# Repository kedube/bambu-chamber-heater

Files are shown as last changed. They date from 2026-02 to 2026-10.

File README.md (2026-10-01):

# Bambu Chamber Heater - ESPHome Temp Controller
ESPHome implementation to remotely control **Sinilink XY-SA/ST series temperature controllers** for *Bambu Lab P1S/X1 Carbon 3D printers*. The repository now supports both the **ESP8285-based XY-WFPOW** module and the **Waveshare ESP32-C6-Zero** from one shared codebase.

This project allows you to automatically manage a chamber heater, link it to print jobs, and control it through Home Assistant or the built-in web interface. It was inspired by the [BambuSauna project](https://makerworld.com/en/models/2417482-bambusauna-for-sinilink-xy-sa-st-temp-controller).

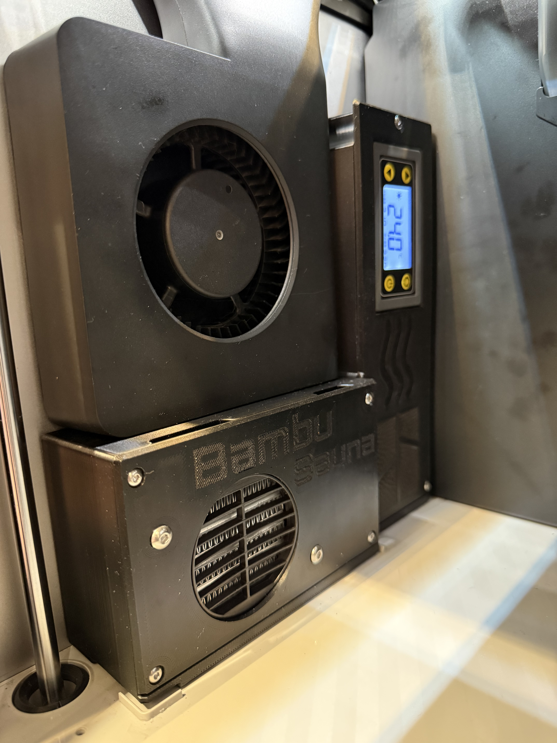
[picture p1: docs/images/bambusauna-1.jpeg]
Assembled BambuSauna chamber heater installed on a Bambu Lab printer

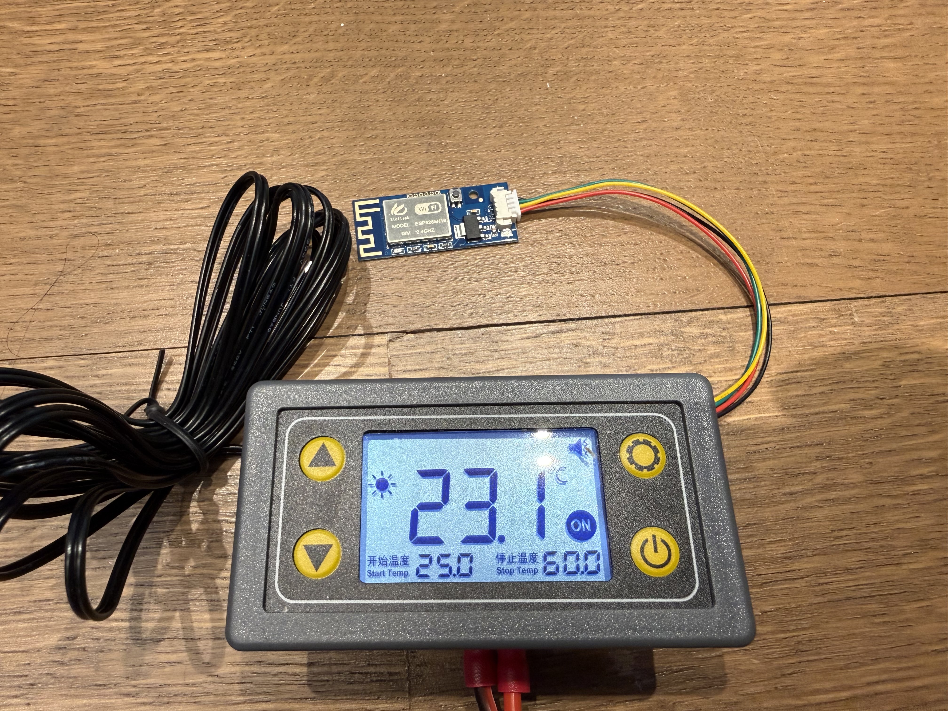
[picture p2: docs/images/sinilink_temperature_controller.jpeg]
Sinilink XY-SA temperature controller module


## Table of Contents

- [Supported Devices](#supported-devices)
- [Features](#features)
- [Filament Presets](#filament-presets)
- [Repository Layout](#repository-layout)
- [Requirements](#requirements)
- [References](#references)
- [Modbus Address Map](#modbus-address-map)
- [Wiring Diagram and Installation Notes](#wiring-diagram-and-installation-notes)
- [Setup](#setup)
  - [1. Install ESPHome](#1-install-esphome)
  - [2. Clone the Repository](#2-clone-the-repository)
  - [3. Configure Secrets](#3-configure-secrets)
  - [4. Choose Device and Temperature Unit](#4-choose-device-and-temperature-unit)
  - [5. Validate the Configuration](#5-validate-the-configuration)
  - [6. Build](#6-build)
  - [7. First Flash](#7-first-flash)
  - [8. Web UI](#8-web-ui)
  - [9. Home Assistant](#9-home-assistant)
- [Troubleshooting](#troubleshooting)
- [Known Issues](#known-issues)
- [Safety](#safety)
- [License](#license)
- [Contributing](#contributing)

## Supported Devices

| Device | ESPHome Entry File | Notes |
| :--- | :--- | :--- |
| ESP8285 / XY-WFPOW | `esphome/temp_controller_esp8285.yaml` | Original Sinilink Wi-Fi module, built-in status LED, no fan RPM monitoring |
| ESP32-C6-Zero | `esphome/temp_controller_esp32.yaml` | External module retrofit, WS2812 status LED, fan RPM monitoring, Wi-Fi protocol sensor |
| Manual selector | `esphome/temp_controller.yaml` | Main YAML with package toggles for device and temperature unit |

## Features

### Shared Features
- ESPHome integration for Home Assistant
- Standalone web interface
- Automatic chamber temperature control based on print state and filament type
- [Filament presets](#filament-presets) plus user-defined mode
- Emergency stop handling
- Over-temperature protection
- Runaway heating detection
- Sensor fault detection
- Modbus communication watchdog
- End-of-job shutoff
- Celsius and Fahrenheit builds
- OTA firmware updates

### ESP32-C6-Zero Extras
- RPM monitoring for 3-wire fans with emergency-stop interlock
- Wi-Fi 6 support with protocol diagnostic sensor via [include/wifi_protocol_helper.h](include/wifi_protocol_helper.h)
- WS2812 RGB status LED (GPIO8) with state-based colors and effects:

| LED State | Color | Effect | Meaning |
|---|---|---|---|
| Emergency Stop | Red | Solid | System emergency stopped |
| WiFi Disconnected | Blue | Fast Pulse | Network connection lost |
| Over Temperature | Red | Strobe | Temperature >60°C warning |
| Heating Active | Orange | Slow Pulse | Heater is running |
| Normal/Idle | Green | Solid (dim) | Everything OK |

The LED updates automatically via state-change triggers (for example Wi-Fi connect/disconnect) plus periodic refresh, providing at-a-glance status without needing to check the web interface or Home Assistant.

## Filament Presets

When a print starts, the controller reads the active filament type from the Bambu Lab Home Assistant integration and automatically selects the matching chamber temperature preset. You can also select a preset manually (including for pre-heating before a print), or use **User-defined** mode to set your own thresholds. Selecting **Off** engages the emergency stop.

Each preset targets the temperature below with a ±1°C hysteresis band (for example, PLA at 22°C starts heating at 21°C and stops at 23°C) to prevent rapid relay cycling. The defaults are defined as substitutions in [esphome/settings.yaml](esphome/settings.yaml) — adjust them there for your filament brands, printer, and enclosure.

| Preset | Default Target (°C) | Preset | Default Target (°C) |
| :--- | :---: | :--- | :---: |
| PLA | 22 | PA | 60 |
| TPU | 25 | PA6 | 80 |
| PETG | 35 | PA12 | 60 |
| PCTG | 35 | PA612 | 25 |
| ABS | 55 | PPA | 70 |
| ASA | 55 | PPS | 80 |
| PC | 80 | PP | 55 |
| PET | 50 | PE | 75 |
| | | PAHT | 55 |

## Repository Layout

- `esphome/settings.yaml` contains the shared substitutions, default build settings, and additional shared configuration options you may want to customize.
- `esphome/packages/controller_shared.yaml` contains the shared controller logic, Modbus entities, automations, and safety behavior.
- `esphome/packages/device_esp8285.yaml` contains ESP8285-only framework, GPIO, and hardware configuration.
- `esphome/packages/device_esp32.yaml` contains ESP32-C6-Zero-only framework, GPIO, fan monitoring, LED logic, and helper include usage.
- `esphome/packages/celsius.yaml` and `esphome/packages/fahrenheit.yaml` contain unit-specific number ranges and preset math.
- `esphome/temp_controller.yaml` is the main entrypoint if you want to switch device and unit by editing one file.
- `include/` contains the shared C++ helper headers used by the YAML lambdas (see [include/README.md](include/README.md)).
- `assets/web/` contains the custom web UI CSS and JavaScript assets used by ESPHome's web server.
- `docs/images/` contains README screenshots, wiring diagrams, and source artwork; `docs/home-assistant-dashboard.md` has a ready-made Lovelace dashboard.
- `hardware/3d-models/` contains printable enclosure and adapter `.3mf` files (print in ASA or PC — see [3D Printed Parts](#3d-printed-parts)).
- `test/` contains host-side unit tests for the helper headers (`./test/run_tests.sh`).
- `.github/workflows/ci.yml` runs the unit tests, validates every device/unit combination, and compiles both device targets on each push.
- `CHANGELOG.md` tracks notable changes for each tagged release.

## Requirements

### Software
- ESPHome installed locally _(validated against ESPHome 2026.9.0 in CI — see [.github/workflows/ci.yml](.github/workflows/ci.yml); older releases may need YAML adjustments)_
- Home Assistant with the [Bambu Lab HA integration](https://github.com/greghesp/ha-bambulab)

### Common Hardware
- Bambu P1S / X1 Carbon 3D Printer
- Sinilink XY-SA10/SA30-W AC 110V-250V Temperature Controller _(the SA10 is sufficient — its 10A relay rating is roughly five times the ~2A a 250W heater draws; the SA30's higher rating is unnecessary here)_
- NOYITO AC 100V-264V to DC 24V 1A Power Supply Module _(powers the 24V Fan only)_
- AC 120/240V PTC Heater 200-250W _(no need to be more powerful than this)_
- (2) 3-Way WAGO Connectors
- 16-18Ga silicone wiring _(Used: red and black wiring)_
- Heat set inserts: (15) M3x4x5 + (1) M2x2.5x3.2
- Screws:
  - (7) M3x5MM or 6MM button screws for covers
  - (2) M3x25MM hex head screws for lower aux fan screws
  - (4) M3x25MM hex head screws for 24V Fan
  - (4) M3x4MM button screws for NOYITO AC to DC Power Supply Module
  - (2) M3x8MM hex head screws to connect housing to printer bottom
  - (4) M4x6MM or 8MM self-tapping screws to hold PTC in housing without fan
  - (2) M4x12MM button screws to hold the PTC heater to the front cover
  - (2) M4 self-locking nuts to connect the PTC heater to the front cover
  - (1) M2x3MM machine screw to hold the wireless module to the housing
- (1) XT30 connector pair set (both ends) _(so the chamber heater can be unplugged and removed from the printer)_
- Heatshrink tubing _(for XT30 connectors)_
- Soldering equipment _(depending on the installation method)_

### ESP8285 Hardware
- Sinilink XY-WFPOW (ESP8285-based) wireless module
- 24V 4020 2-wire fan _(Used: SUNON MF40202VX-1000U-A99 with 10.8CFM airflow)_
- USB-to-TTL UART programmer _(only needed for the initial flash; highly recommend FTDI-based programmers)_

### 3D Printed Parts
Print the enclosure and adapter parts in `hardware/3d-models/` in **ASA or PC only**. The housing sits against a 200-250W PTC heater and a printer that may itself run a heated chamber — PLA and PETG will soften and deform at these temperatures.

### ESP32-C6-Zero Hardware
- Waveshare ESP32-C6-Zero with 2 x 9-pin headers soldered
- 24V 4020 3-wire fan _(Used: SUNON MF40202VX-1000U-G99 with 10.8CFM airflow)_
- 1/4W 10K resistor _(for 3.3V pull-up power for tach)_
- JST MX 1.25mm 4-pin cable to connect ESP32 to Temperature Controller
- Assorted 2.54mm pitch housings and crimp pins to terminate JST MX 4-Pin cable
- USB-C-to-USB-C cable for the initial flash

## References
- [Sinilink XY-ST/SA Remote Thermostat Datasheet](https://myosuploads3.banggood.com/products/20240220/20240220213226STSA-EN.pdf)
- [Sinilink XY-WT04 Modbus Communication Protocol](https://myosuploads3.banggood.com/products/20220717/20220717212911XY-WT04-EN.pdf)
- [ESPhome-Sinilink-XY-WFPOW](https://github.com/creepystefan/ESPhome-Sinilink-XY-WFPOW)
- [Tasmota XY-WFPOW Template](https://templates.blakadder.com/sinilink_XY-WFPOW.html)

## Modbus Address Map

| ADDRESS | TYPE | NAME | RANGE/VALUES | Read/Write | DESCRIPTION |
| :--- | :---: | :--- | :--- | :---: | :--- |
| 0x0000 | U_WORD | Controller Status | 0=Stopped, 1=Active | RW | Main relay/controller state |
| 0x0001 | U_WORD | Temp Sensor Status | 0=Connected, 1=Disc | RO | Temperature sensor connection status |
| 0x0002 | U_WORD | Delay Time Remaining | 0-999 seconds | RO | Countdown timer for delayed start |
| 0x0003 | S_WORD | Current Temperature | -400 to 1100 (*0.1) | RO | Current measured temperature |
| 0x0004 | U_WORD | Temperature Unit | 0=Celsius, 1=Fahrenheit | RW | Display and control temperature unit |
| 0x0005 | U_WORD | Controller Mode | 0=Heating, 1=Cooling | RO | Operating mode |
| 0x0006 | S_WORD | Low Temp Threshold | -400 to 850 (*0.1) | RW | Temperature to start heating/cooling |
| 0x0007 | S_WORD | High Temp Threshold | -400 to 850 (*0.1) | RW | Temperature to stop heating/cooling |
| 0x0008 | S_WORD | High Temp Alarm | -400 to 1100 (*0.1) | RW | High temperature alarm threshold |
| 0x0009 | S_WORD | Low Temp Alarm | -400 to 1100 (*0.1) | RW | Low temperature alarm threshold |
| 0x000A | U_WORD | Delay Start Time | 0-999 seconds | RW | Delay start duration setting |
| 0x000B | S_WORD | Temperature Offset | -100 to 100 (*0.1) | RW | Temperature calibration offset |
| 0x000C | BOOL | Alarm Active | 0=No, 1=Yes | RO | Temperature alarm status |
| 0x000D | BOOL | Alarm Sound | 0=Off, 1=On | RW | Enable/disable alarm beeper |
| 0x000E | BOOL | High Temp Alarm Enable | 0=Off, 1=On | RW | Enable high temperature alarm |
| 0x000F | BOOL | Low Temp Alarm Enable | 0=Off, 1=On | RW | Enable low temperature alarm |
| 0x0010 | BOOL | Delay Start Enable | 0=Off, 1=On | RW | Enable delayed start feature |
| 0x0011 | BOOL | Emergency Stop | 0=Off, 1=On | RW | Emergency stop/disable controller |
| 0x0012 | U_WORD | Modbus Address | 1-247 | RW | Modbus slave address |
| 0x0013 | U_WORD | Modbus Baudrate | 0-6 | RW | Serial communication speed |
| 0x0014 | BOOL | Sleep Mode | 0=Off, 1=On | RW | Display sleep/power saving mode |
| 0x0015 | U_WORD | Backlight Level | 0-7 | RW | Display backlight brightness |

Baudrate map for `0x0013`: `0=9600`, `1=14400`, `2=19200`, `3=38400`, `4=56000`, `5=57600`, `6=115200`.

Temperature Value Encoding:
   - Stored as signed 16-bit integers representing temperature in tenths of degrees
   - Actual temperature = register_value * 0.1
   - Example: register value 235 = 23.5°C

Safety Notes:
   - Always enable high temp alarm (0x000E) for safety
   - Set high temp alarm (0x0008) above normal operating range
   - Emergency stop (0x0011) immediately disables heating/cooling

## Wiring Diagram and Installation Notes

### ESP8285 / XY-WFPOW
Use the original Sinilink XY-WFPOW Wi-Fi module. The basic wiring diagram is shown below.

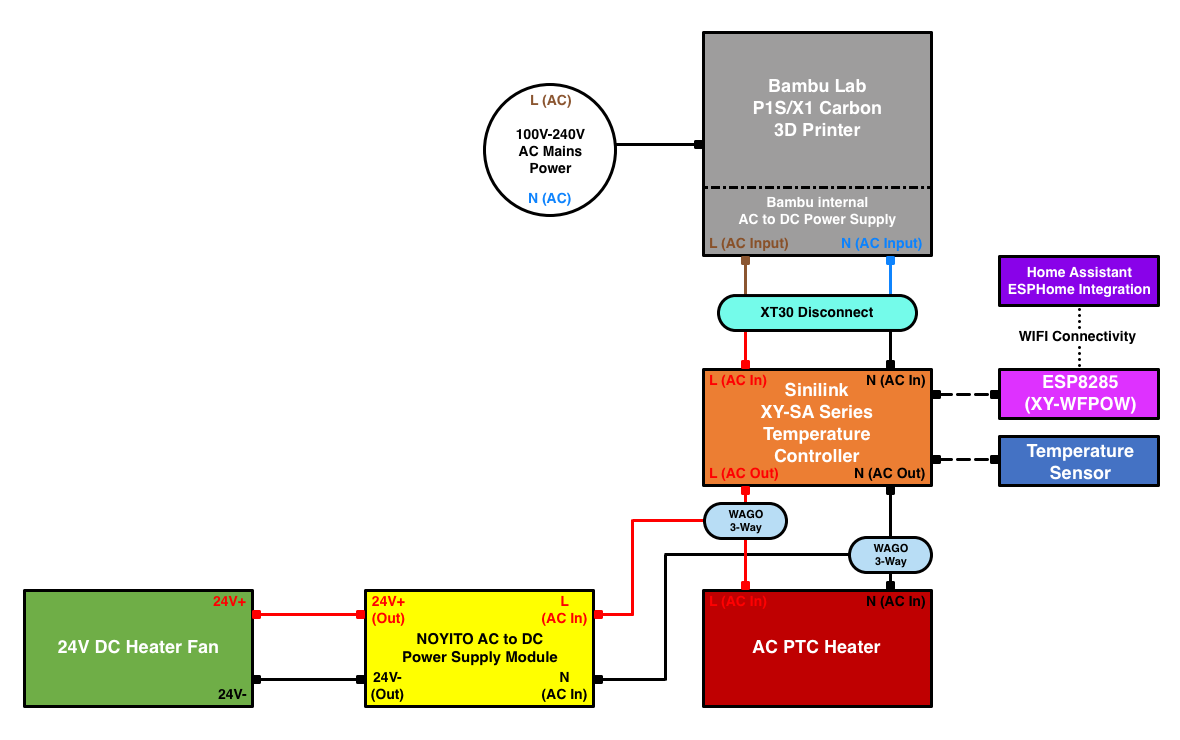
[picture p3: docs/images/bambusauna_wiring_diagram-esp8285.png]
ESP8285 / XY-WFPOW wiring diagram

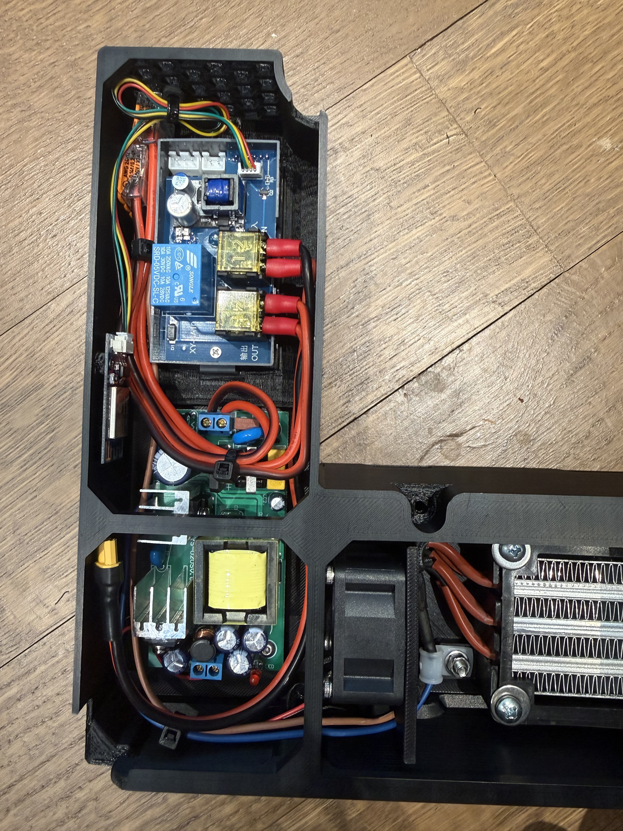
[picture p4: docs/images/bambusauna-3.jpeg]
Heater housing interior showing the Sinilink controller and wiring

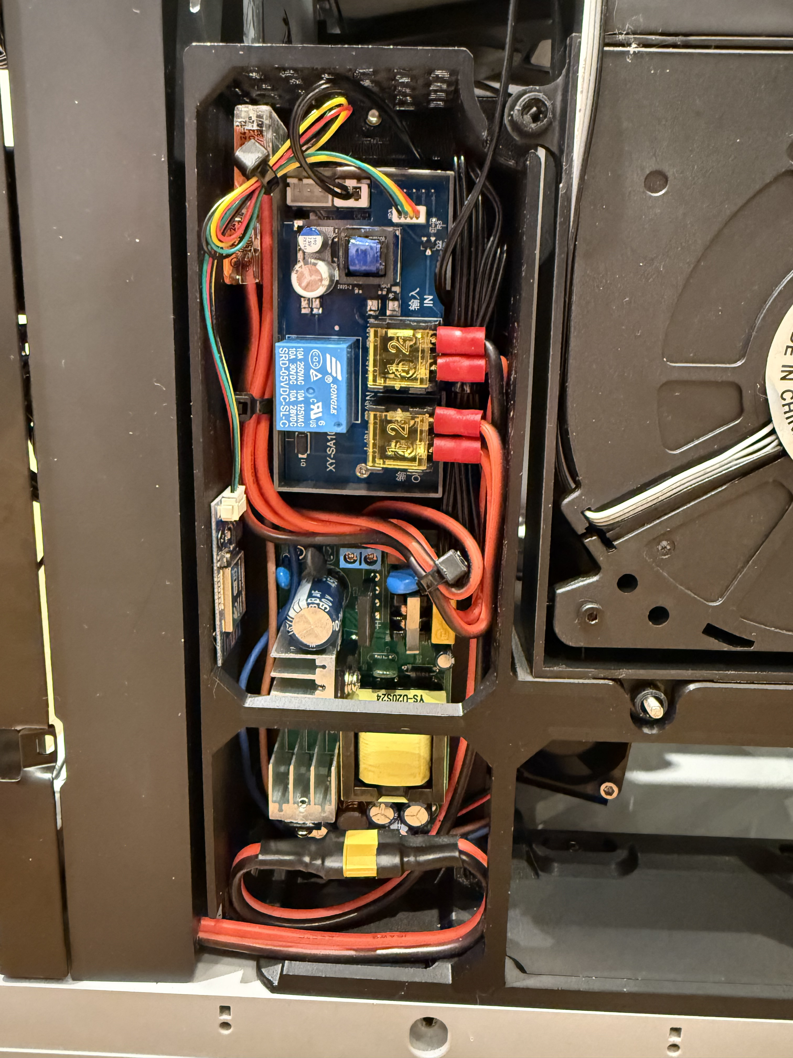
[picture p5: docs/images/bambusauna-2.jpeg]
Assembled heater housing mounted beneath the printer


### ESP32-C6-Zero
The ESP32-C6-Zero retrofit uses a separate module and adds fan RPM monitoring and RGB LED status indication.

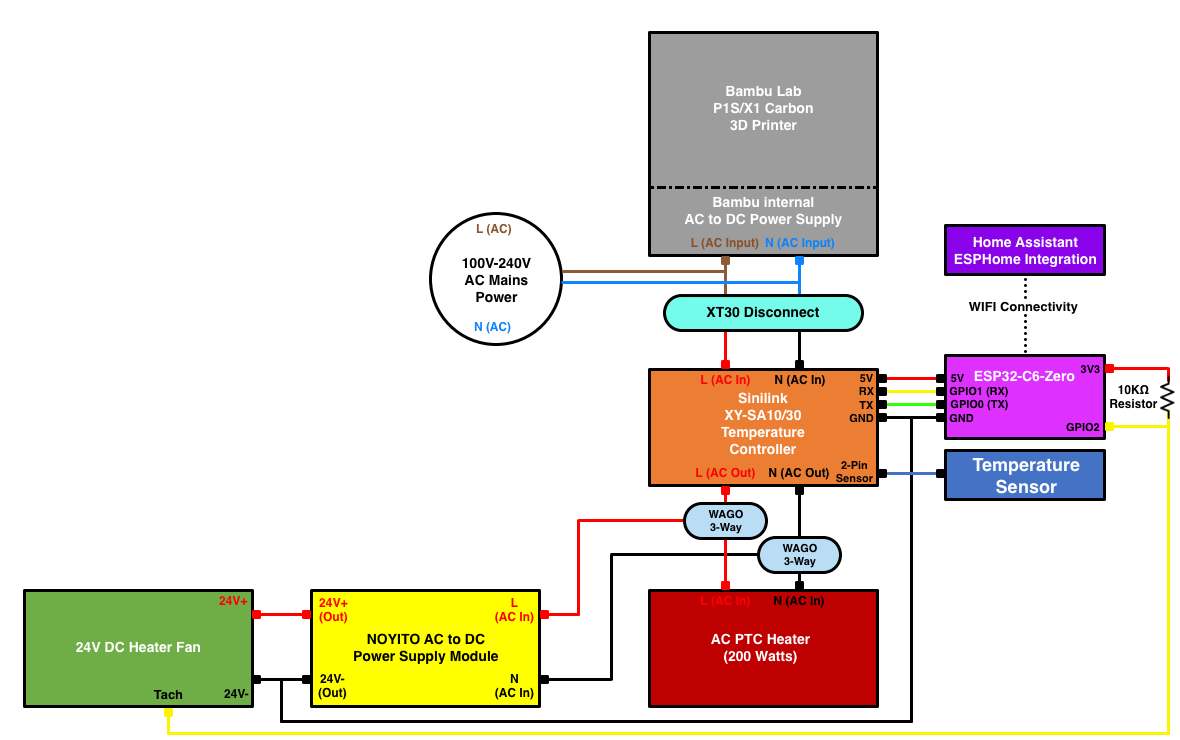
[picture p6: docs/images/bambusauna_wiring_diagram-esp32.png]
ESP32-C6-Zero wiring diagram

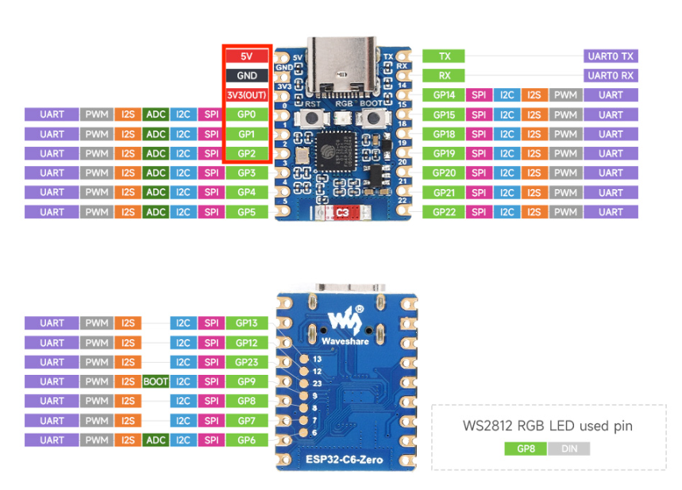
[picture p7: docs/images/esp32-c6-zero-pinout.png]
Waveshare ESP32-C6-Zero pinout reference

ESP32-C6-Zero wiring harness with JST connector
Heater housing interior with the ESP32-C6-Zero installed
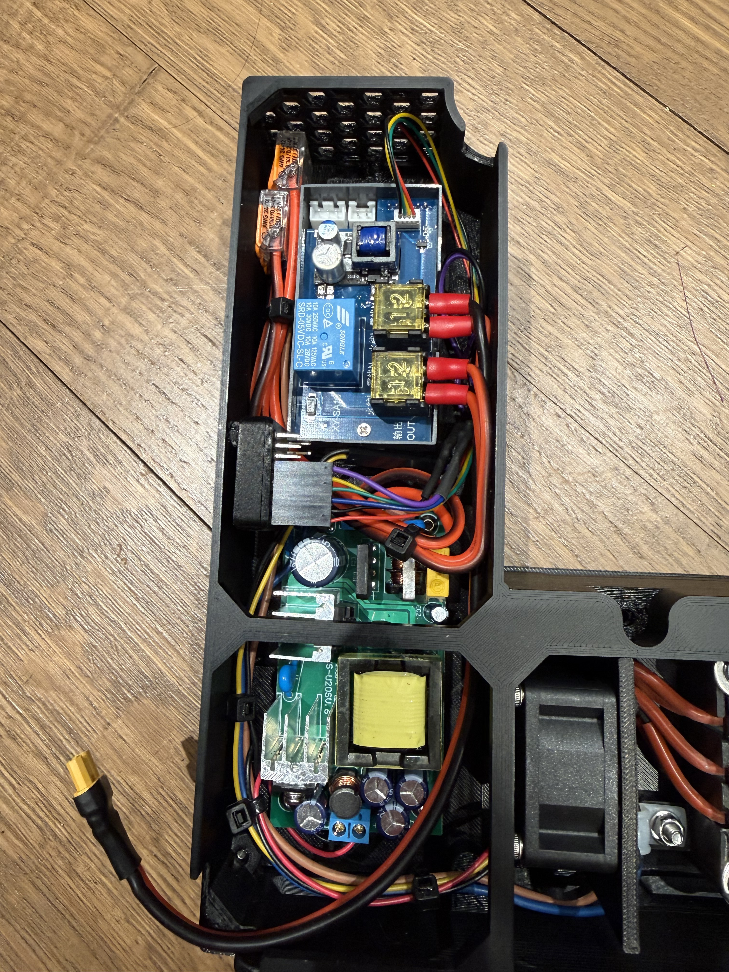
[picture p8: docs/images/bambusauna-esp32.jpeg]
Close-up of the ESP32-C6-Zero module mounted in the housing


## Setup

### 1. Install ESPHome
Follow the official directions on the [ESPHome website](https://esphome.io/guides/installing_esphome/).

On macOS, the easiest path is [Homebrew](https://brew.sh/). If you don't already have Homebrew, install it first:
```bash
/bin/bash -c "$(curl -fsSL https://raw.githubusercontent.com/Homebrew/install/HEAD/install.sh)"
```

Then install ESPHome:
```bash
brew install esphome
```

### 2. Clone the Repository

```bash
git clone https://github.com/kedube/bambu-chamber-heater
cd bambu-chamber-heater
```

### 3. Configure Secrets
Copy and edit the secrets file:

```bash
cp esphome/secrets-example.yaml esphome/secrets.yaml
```

Important values include:
- `wifi_ssid`
- `wifi_password`
- `ap_wifi_ssid`
- `ap_wifi_password`
- `web_server_username`
- `web_server_password`
- `ota_password`
- `encryption_key`
- `bambu_printer_id`

The example file also contains commented-out keys (`static_ip`, `gateway`, `subnet`, `dns1`, `dns2`) for an optional static IP configuration — uncomment them (and the matching `manual_ip:` block in `esphome/packages/controller_shared.yaml`) if you need one.

Shared substitutions such as `device_name`, `friendly_name`, software version, and filament preset defaults are defined in `esphome/settings.yaml`.
Most runtime behavior, Modbus transport settings, and automations are defined in `esphome/packages/controller_shared.yaml`.
Use those files for shared configuration changes before editing device-specific packages.

Generate a valid 32-byte encryption key (see: [ESPHome.io](https://esphome.io/components/api/)), and insert it under `encryption_key`.

### 4. Choose Device and Temperature Unit

If you want one editable selector file, use `esphome/temp_controller.yaml` and switch the package includes:

```yaml
packages:
  settings: !include settings.yaml
  controller_shared: !include packages/controller_shared.yaml
  select_units: !include
    file: packages/celsius.yaml
    #file: packages/fahrenheit.yaml
  select_device: !include
    file: packages/device_esp8285.yaml
    #file: packages/device_esp32.yaml
```

If you prefer a fixed compile target, use one of these:
- `esphome/temp_controller_esp8285.yaml`
- `esphome/temp_controller_esp32.yaml`

### 5. Validate the Configuration

```bash
esphome config esphome/temp_controller.yaml
```

### 6. Build

Example:

```bash
esphome run esphome/temp_controller.yaml
```

### 7. First Flash

Once ESPHome successfully compiles the YAML configuration, it will prompt you to flash the module. For the first flash, the device must be connected to your computer to upload the firmware.

#### ESP8285 / XY-WFPOW
For the ESP8285, use the USB-to-TTL adapter programmer at **3.3V** and the XY-WFPOW flashing pins:

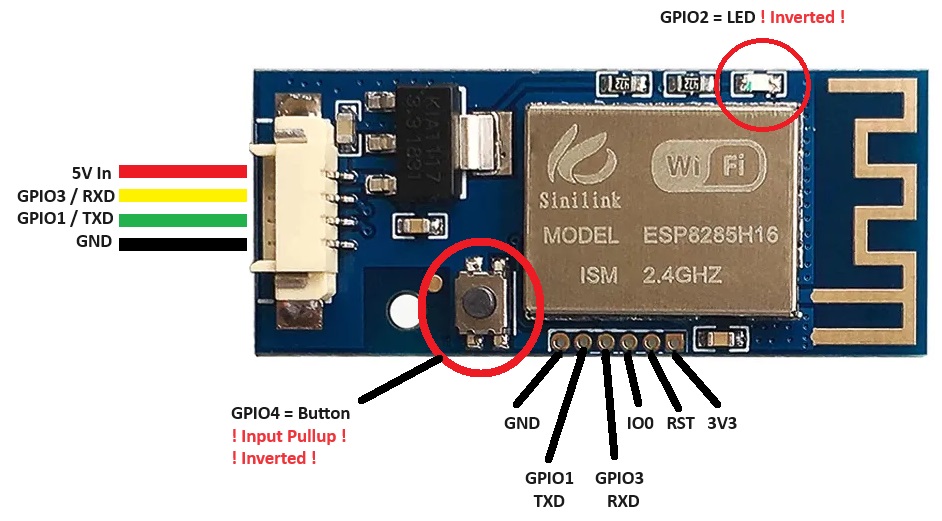
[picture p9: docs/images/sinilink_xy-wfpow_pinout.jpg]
Sinilink XY-WFPOW flashing pinout (source: creepystefan/ESPhome-Sinilink-XY-WFPOW)

```text
GND -> GND
TXD -> RXD
RXD -> TXD
IO0 -> GND
RST -> not connected
3V3 -> VCC
```

Adapter board photos:
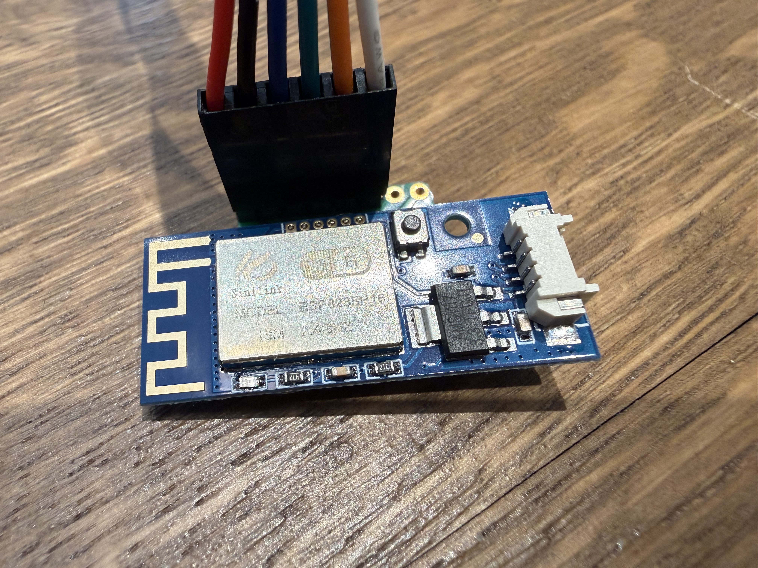
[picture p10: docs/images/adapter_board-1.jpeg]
USB-to-TTL programming adapter board, top view

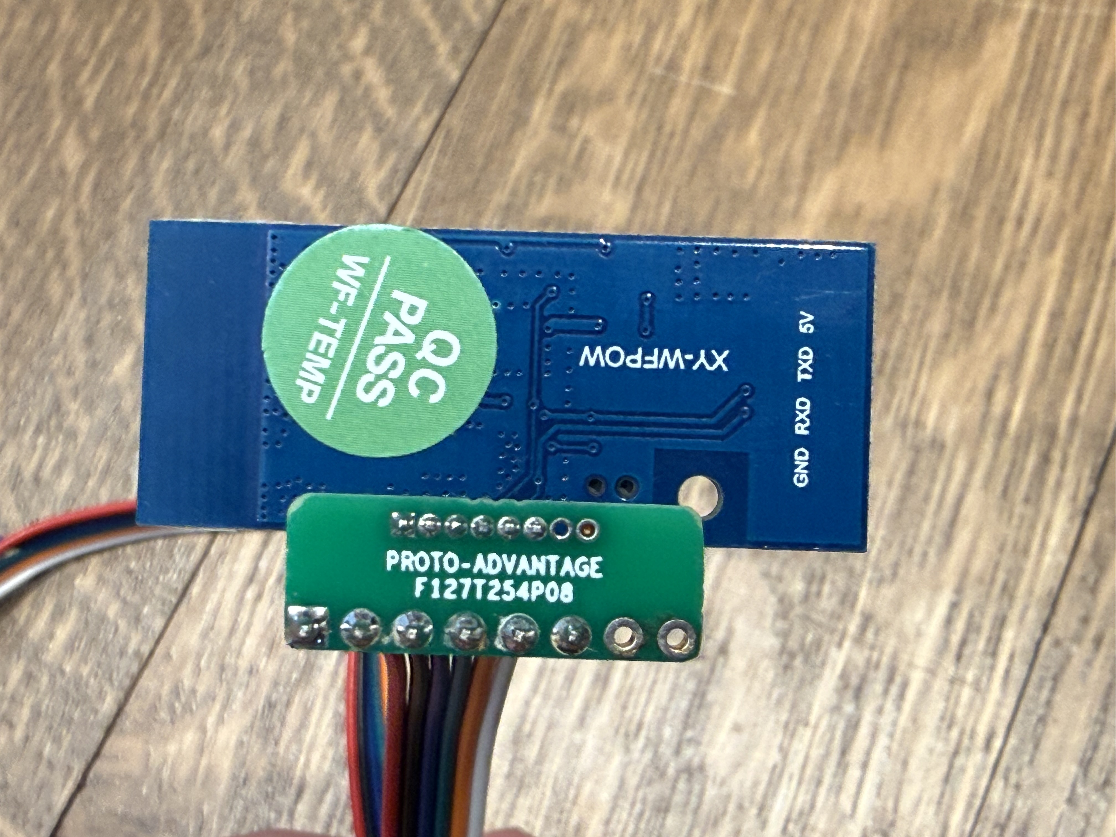
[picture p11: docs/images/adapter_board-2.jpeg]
USB-to-TTL programming adapter board connected to the XY-WFPOW


#### ESP32-C6-Zero
For the ESP32-C6-Zero, you must connect the board via USB-C and flash it directly. It will prompt you after a successful build for where to upload the code. Once running, the onboard WS2812 RGB LED shows live system status — see the [LED state table](#esp32-c6-zero-extras) under Features.

#### Upload Firmware Over USB With ESPHome

```text
INFO Build Info: config_hash=0x694d2e36 build_time_str=2026-04-01 14:02:17 -0400
INFO Successfully compiled program.
Found multiple options for uploading, please choose one:
  [1] /dev/cu.usbserial-8320 (USB Serial)
  [2] Over The Air (esp32-remote.local)
(number):
```

#### Subsequent Flashes
After the initial flash, both device types can be updated over the air (OTA) using ESPHome.

### 8. Web UI
A local web server starts on port `80` after installation. You can access it from a browser on your local network using the username and password configured in `secrets.yaml`.

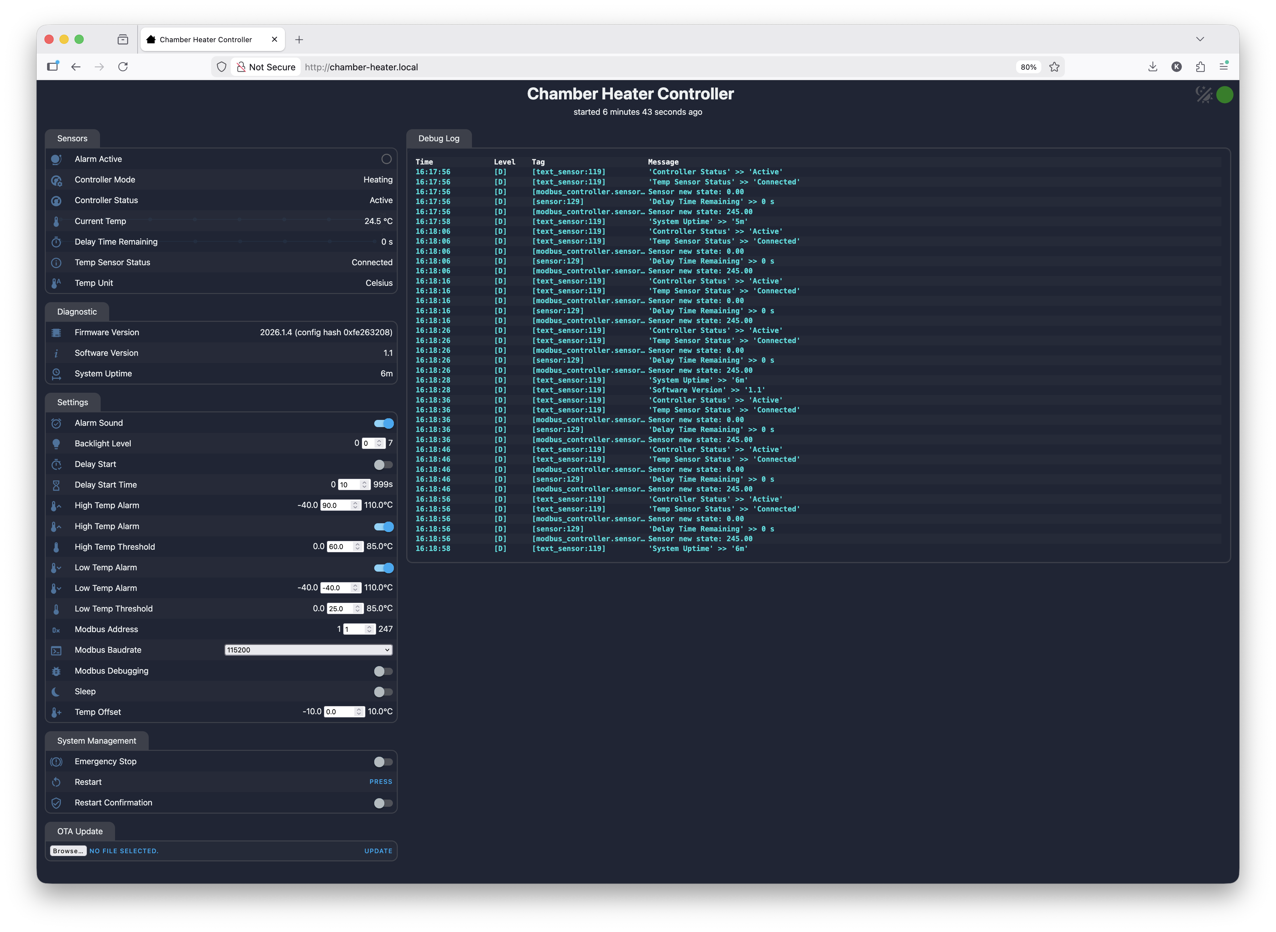
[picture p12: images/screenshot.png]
Chamber heater web interface showing sensors, settings, and system controls


The web UI's animated background is selectable in `esphome/packages/controller_shared.yaml` under `web_server:` → `js_include`. Three effects ship in `assets/web/`: `pixel-stars.js` (default), `moving-particles.js`, and `shooting-stars.js` — uncomment the one you want (only one at a time) and re-flash.

### 9. Home Assistant
Once online, the device should be discovered by the ESPHome integration in Home Assistant. Use the same `encryption_key` configured in `esphome/secrets.yaml`.

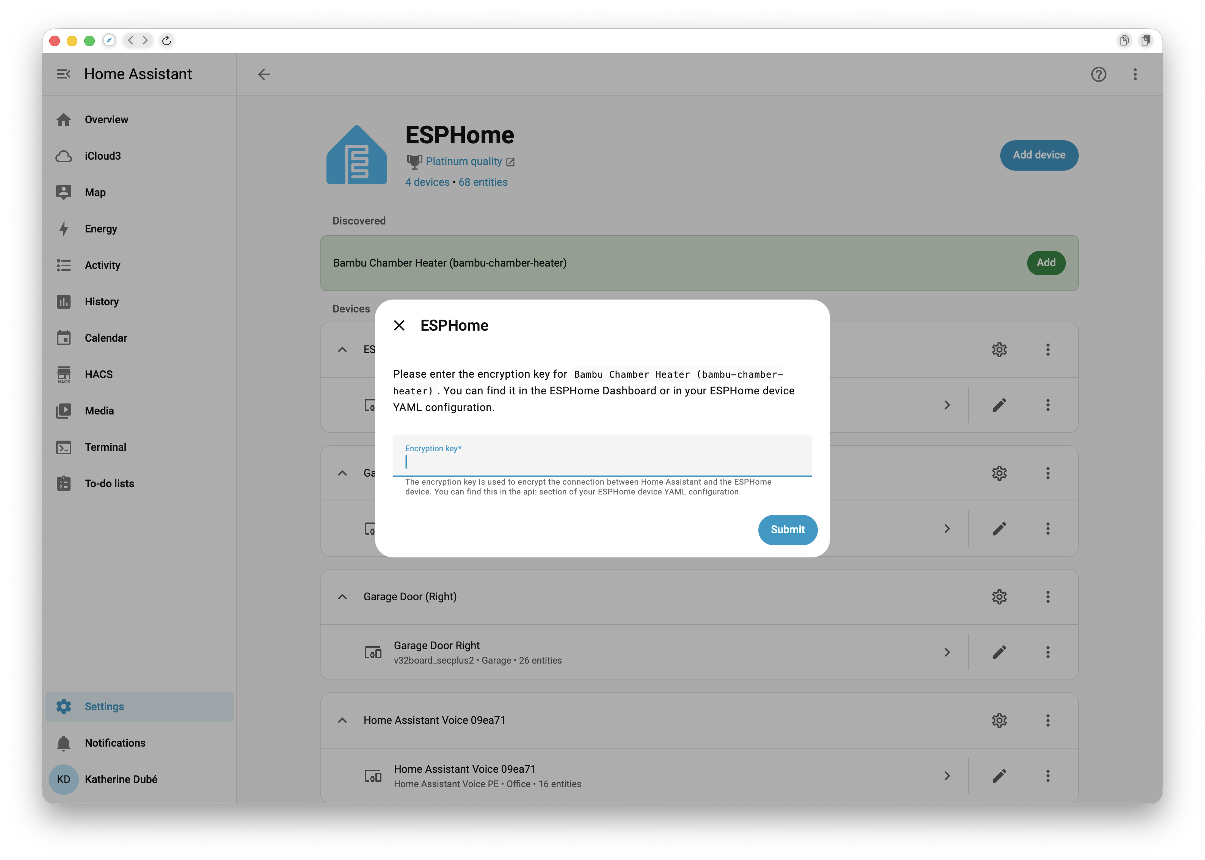
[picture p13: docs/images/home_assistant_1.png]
Home Assistant prompting for the ESPHome encryption key

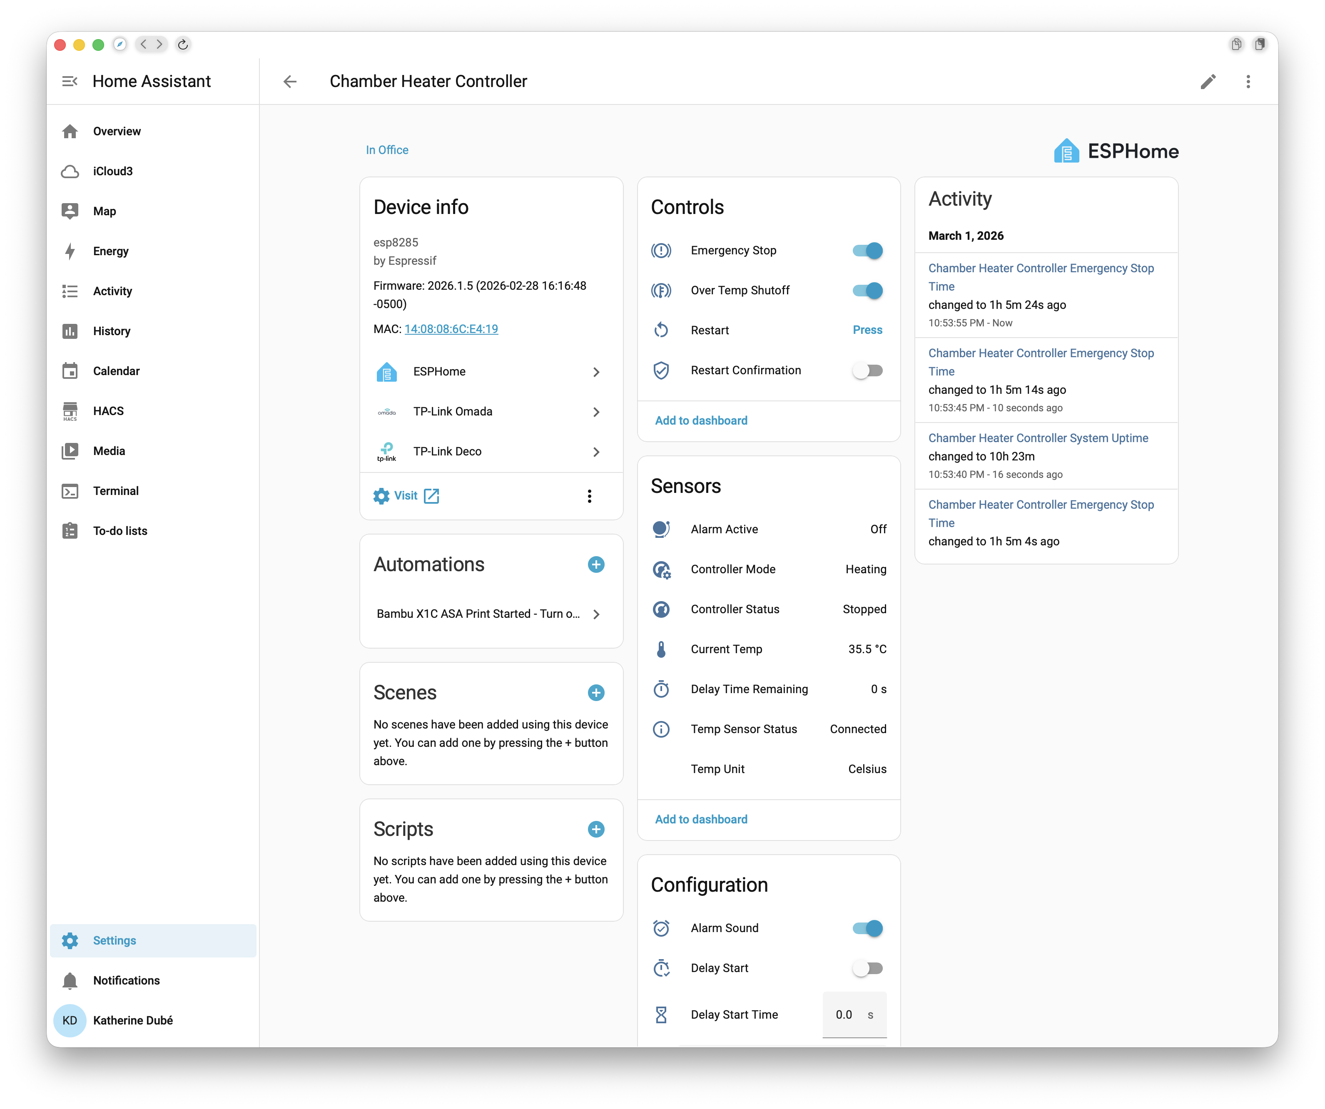
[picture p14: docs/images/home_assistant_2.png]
Home Assistant device page listing the chamber heater entities


For a ready-made dashboard layout (gauge, controls, and safety diagnostics), see [docs/home-assistant-dashboard.md](docs/home-assistant-dashboard.md).

## Troubleshooting

**The device boots with Emergency Stop engaged.** This is by design — the heater always starts disarmed. Select a filament preset (or clear the Emergency Stop switch) to begin heating.

**Emergency Stop is on and selecting a preset doesn't clear it.** When the stop was triggered by a fault — thermal runaway, a temperature alarm, a disconnected sensor, Modbus communication loss, a fan failure, the printer going offline, or Home Assistant disconnecting — presets intentionally cannot clear it (the log shows *"Emergency stop remains active because it was triggered by a fault condition"*). Fix the underlying issue, then manually turn off the **Emergency Stop** switch in the web UI or Home Assistant to acknowledge the fault. The **Emergency Stop Time** sensor (System Management group) shows how long ago it tripped, and the device logs record the cause on lines tagged `EMERGENCY`.

**Heater won't turn on.** Check, in order: the **Filament Temp Preset** isn't `Off`; **Emergency Stop** is off; **Delay Start** isn't holding the relay (watch **Delay Time Remaining**); and the current temperature isn't already above the **High Temp Threshold**. Note that when the printer reports an inactive state (finish, failed, offline, or idle), the end-of-job shutoff forces the preset back to `Off` — you can still pre-heat manually by selecting a preset, but a printer state change to inactive will turn it off again.

**"No temperature updates" emergency stop (Modbus watchdog).** The watchdog trips if no temperature reading arrives for 90 seconds. Verify the UART wiring (TX/RX not swapped), that the controller's baud rate matches the build default of 115200, and that the Modbus address is 1. Turn on the **Modbus Debugging** switch to log the raw hex frames and confirm whether the controller is responding.

**Fan failure emergency stop, or Fan RPM reads 0 (ESP32-C6-Zero).** A fan fault trips when RPM stays below 200 for 10 seconds while the heater is active. Confirm the fan is a 3-wire model with a tachometer lead, the tach line has its 10K pull-up to 3.3V, and the JST harness is seated. The thresholds (`fan_min_rpm`, `fan_fail_timeout_seconds`) are adjustable in `esphome/settings.yaml`.

**Emergency stop whenever Home Assistant restarts or drops off the network.** Losing the Home Assistant API connection (or the printer's `_online` sensor going off) is treated as a fail-safe condition because print-state automation is no longer available. This is expected; clear the stop once Home Assistant reconnects. Check the **WIFI Signal Strength** sensor if it happens frequently.

**Can't reach the web UI.** If the device can't join your Wi-Fi it starts a fallback access point (default SSID `chamber-heater`, configurable via `ap_wifi_ssid`) with a captive portal for reconfiguration. The web UI itself is on port 80 and uses the credentials from `secrets.yaml`.

**The Restart button does nothing.** Turn on the **Restart Confirmation** switch first, then press **Restart** within 10 seconds — this guards against accidental restarts mid-print.

## Known Issues
- The Sinilink Modbus addresses for the sleep switch (`0x0014`) and backlight level (`0x0015`) do not seem to have any effect on the backlight settings for XY-SA10/SA30 controllers.
- Mixed-material prints will cause the chamber target temperature to fluctuate as the active filament changes.

## Safety
The author assumes no liability for injury, damage, or loss resulting from wiring errors, improper installation, or misuse of this project. Electrical work can be hazardous. If you are unsure, consult a qualified professional.

## License
This project is licensed under the GNU General Public License v3.0 or later — see [LICENSE](LICENSE).

## Contributing
Contributions are welcome for bug fixes, documentation improvements, and new hardware support. Please include testing details when possible, and add user-visible changes to the `## Unreleased` section of [CHANGELOG.md](CHANGELOG.md) — the release automation turns that section into the published release notes.

### Release Process
Releases are fully automated by [.github/workflows/release.yml](.github/workflows/release.yml):

1. Every push to `main` runs [CI](.github/workflows/ci.yml) (unit tests, ESPHome validation for all device/unit combinations, and firmware compiles).
2. When CI passes, the Release workflow bumps the patch segment of `sw_version` in `esphome/settings.yaml`, rotates the CHANGELOG's `## Unreleased` section into the new version, and pushes a `chore(release): <version> [skip ci]` commit.
3. A GitHub release is published for that version, with notes generated from the CHANGELOG section (Highlights), the commit list since the previous tag, and a full-changelog compare link.

To cut a **minor or major** release, set `sw_version` yourself in a normal commit (e.g. `1.9.0`); because that version has no tag yet, the automation publishes it exactly as set, then resumes patch bumps. To re-publish a release for the current version (for example after a failed run), use the Release workflow's **Run workflow** button.

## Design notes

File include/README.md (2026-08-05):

# Helper Headers

C++ helpers included by the ESPHome YAML packages (see the `esphome:` → `includes:` lists in `esphome/packages/`). Keeping this logic in headers keeps the YAML lambdas short and lets both device targets share one implementation.

| Header | Used by | Purpose |
| :--- | :--- | :--- |
| `api_client_helper.h` | `controller_shared.yaml` | Classifies ESPHome API clients (Home Assistant vs. log viewers vs. other) so the Home Assistant disconnect safety trigger doesn't fire when a log viewer disconnects. |
| `preset_helper.h` | `controller_shared.yaml`, `celsius.yaml`, `fahrenheit.yaml` | Filament preset table lookup, Bambu filament-type → preset-name mapping, and threshold update helpers. |
| `printer_state_helper.h` | `controller_shared.yaml` | Maps Bambu printer status strings to "actively printing" / "inactive" for the auto-heat and end-of-job shutoff logic. |
| `status_led_helper.h` | `device_esp32.yaml` | Computes the WS2812 status LED mode (emergency stop, Wi-Fi lost, over-temp, heating, idle) from system state. |
| `wifi_protocol_helper.h` | `device_esp32.yaml` | Reads the negotiated Wi-Fi PHY mode (802.11b/g/n/ax) from ESP-IDF for the Wi-Fi protocol diagnostic sensor. |

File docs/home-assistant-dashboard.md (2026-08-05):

# Home Assistant Dashboard Example

A ready-to-paste Lovelace layout for the chamber heater. It groups the entities the way you'll actually use them: current status at the top, day-to-day controls in the middle, and safety/diagnostics at the bottom.

> **Entity IDs:** The IDs below assume the default `friendly_name: "Chamber Heater Controller"` from `esphome/settings.yaml`. If you changed it, or Home Assistant assigned different IDs, check the actual IDs under **Settings → Devices & Services → ESPHome → your device** and adjust. The `Fan Speed` sensor only exists on ESP32-C6-Zero builds — delete that row for ESP8285 builds.

Add a **Manual** card to your dashboard and paste:

```yaml
type: vertical-stack
cards:
  - type: gauge
    name: Chamber Temperature
    entity: sensor.chamber_heater_controller_current_temp
    unit: "°C"
    min: 0
    max: 85
    needle: true
    severity:
      green: 0
      yellow: 60
      red: 70

  - type: entities
    title: Chamber Heater
    entities:
      - entity: select.chamber_heater_controller_filament_temp_preset
        name: Filament Preset
      - entity: sensor.chamber_heater_controller_controller_status
        name: Heater Status
      - entity: number.chamber_heater_controller_low_temp_threshold
        name: Start Heating Below
      - entity: number.chamber_heater_controller_high_temp_threshold
        name: Stop Heating At
      - entity: sensor.chamber_heater_controller_printer_status
        name: Printer Status

  - type: entities
    title: Safety & Diagnostics
    entities:
      - entity: switch.chamber_heater_controller_emergency_stop
        name: Emergency Stop
      - entity: switch.chamber_heater_controller_over_temp_shutoff
        name: Over Temp Shutoff
      - entity: number.chamber_heater_controller_high_temp_alarm
        name: High Temp Alarm
      - entity: binary_sensor.chamber_heater_controller_alarm_active
        name: Alarm Active
      - entity: sensor.chamber_heater_controller_emergency_stop_time
        name: Emergency Stop Tripped
      - entity: sensor.chamber_heater_controller_fan_speed
        name: Fan Speed
      - entity: sensor.chamber_heater_controller_temp_sensor_status
        name: Temp Sensor
```

Notes:

- For **Fahrenheit builds**, change the gauge `unit` to `°F` and scale `min`/`max`/`severity` accordingly (e.g. max 185, yellow 140, red 158).
- A history-graph card for `sensor.chamber_heater_controller_current_temp` alongside the printer's chamber temperature sensor from the [Bambu Lab integration](https://github.com/greghesp/ha-bambulab) is handy for tuning presets:

```yaml
type: history-graph
title: Chamber Temperature History
hours_to_show: 6
entities:
  - sensor.chamber_heater_controller_current_temp
```

- Everything here is also available without Home Assistant via the built-in web UI on port 80.

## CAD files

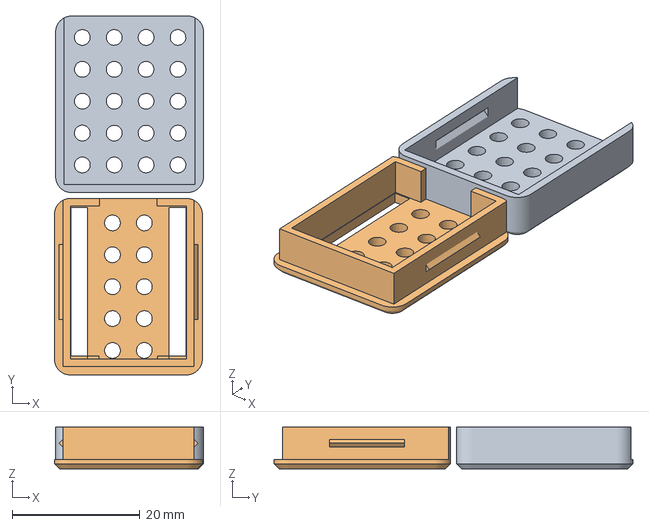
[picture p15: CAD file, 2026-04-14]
hardware/3d-models/esp32-c6_zero.3mf
23.4 x 56.3 x 6.55 mm
ESP32-C6-Zero_Lid.stl
ESP32-C6-Zero_Base.stl

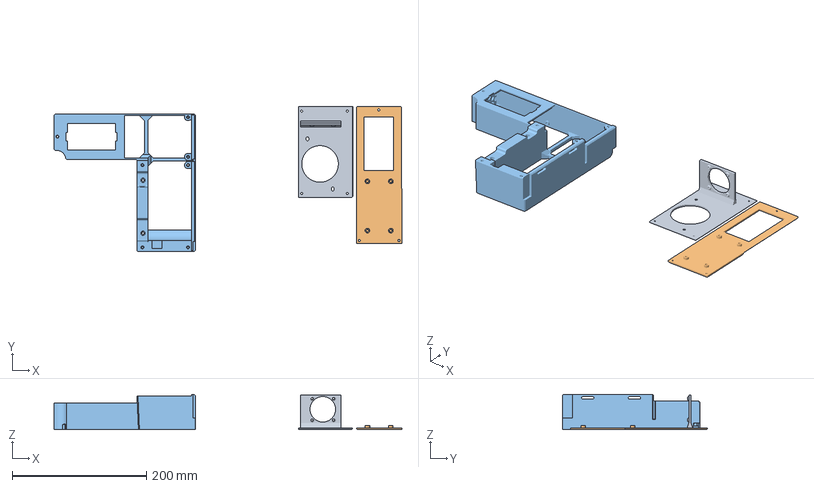
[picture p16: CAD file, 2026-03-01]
hardware/3d-models/BambuSauna_for_Sinilink.3mf
519.3 x 216.5 x 52.5 mm
BambuSauna_Heater_Cover.stl
BambuSauna_Controller_Cover.stl
BambuSauna_Housing.stl

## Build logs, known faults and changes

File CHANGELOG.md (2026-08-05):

# Changelog

Notable changes for each tagged release. Versions correspond to git tags and to the `sw_version` substitution in `esphome/settings.yaml`.

## 1.8.1 — 2026-08-05
- **Fixed:** Fahrenheit builds applied Celsius-valued safety thresholds. The runaway-detection rate limit and the ESP32 over-temperature LED threshold now live in the unit packages with converted values (`0.9°F/s`, `140°F`) — previously a Fahrenheit ESP32 build showed the over-temperature strobe above 60°F (~15.6°C), i.e. at room temperature.
- **Fixed:** Removed the `disable_crc` Modbus option, which was removed from ESPHome and failed validation on 2026.7.
- Added GitHub Actions CI: host unit tests, `esphome config` for all device/unit combinations, and `esphome compile` for both device targets (pinned to ESPHome 2026.7.2).
- Added host-side unit tests for the `include/` helper headers (`./test/run_tests.sh`).
- Added a Home Assistant Lovelace dashboard example (`docs/home-assistant-dashboard.md`), a GitHub bug-report template, and README/CHANGELOG documentation improvements.
- Clarified that `platformio.ini` exists only for IDE IntelliSense; firmware builds go through the ESPHome CLI.
- Added an automated release process: after CI passes on `main`, the Release workflow bumps `sw_version`, rotates this changelog's Unreleased section into the new version, and publishes a GitHub release with generated notes (highlights + commit list). CI also gained manual dispatch, a weekly schedule, and a latest-ESPHome canary job.

## 1.8.0 — 2026-07-11
- Performance improvements and code optimizations.

## 1.7.6 — 2026-06-05
- Fixed an end-of-job race where a finished print could set the preset to `Off` and then immediately re-select a filament preset, leaving the heater running.

## 1.7.5 — 2026-05-04
- Compatibility updates for ESPHome 2026.4.

## 1.7.4 — 2026-04-15
- GPIO pin assignments are now configurable in the device-specific YAML files.
- Removed duplicated code between device packages.

## 1.7.3 — 2026-04-14
- Restored the ability to manually pre-heat the chamber when the printer is not printing.
- Streamlined several safety checks.

## 1.7.2 — 2026-04-14
- Fixed status LED usage before the system is ready.
- Improved Home Assistant API disconnect handling.
- Fan-failure faults now only trigger while a print is active.
- Updated wiring diagram sources and the 3D model.

## 1.7.1 — 2026-04-13
- Fan tach now relies on the external pull-up resistor; removed the internal pull-up configuration.

## 1.7.0 — 2026-04-02
- Major refactor merging the ESP32 and ESP8285 codebases into one shared package structure (`esphome/packages/`).
- Cleaned up the repository directory layout and documentation.

## 1.6.x — 2026-03-18 to 2026-03-21
- Added ESP32-C6-Zero support (initially as parallel `*.esp32` tags): fan RPM monitoring with a failure latch that prevents the heater from running with a failed fan, WS2812 status LED, and updated wiring diagrams.
- Hardened emergency-stop handling so faults cannot be overridden while the underlying condition persists.
- Optimized fault detection and safety logging.

## 1.5.x — 2026-02-18 to 2026-03-01
- Added print-state automations: filament-type presets auto-select when a print starts, and the heater shuts off when a print finishes or is canceled.
- Expanded the supported filament types and refactored presets to be modular.
- Improved emergency-stop handling during communication errors with Home Assistant and the Bambu Lab integration.
- Numerous performance and memory optimizations; updated hardware and installation documentation.

## 1.4.x — 2026-02-14 to 2026-02-16
- Documented the Modbus address map and safety notes.
- Improved fault handling, thermal-overrun handling, and a cooling-mode bug fix.
- Human-readable emergency stop time output.

## 1.3 — 2026-02-12
- Initial public release for the Sinilink XY-WFPOW (ESP8285).

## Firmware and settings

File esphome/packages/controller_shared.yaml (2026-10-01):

#
# Bambu Chamber Heater Modbus Controller for Sinilink XY-SA/ST series temperature controllers.
# Shared controller logic for ESP8285 (XY-WFPOW) and ESP32-C6-Zero device targets.
# Copyright (C) 2026    Katherine Dubé
#
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

substitutions:
  # Text sensor filter that drops publishes when the value is unchanged, so
  # identical state isn't re-sent to the API and web server on every modbus poll.
  # (Filament type aliases live in include/preset_helper.h - lookup_filament_preset_name)
  text_dedup_filter: "static std::string last_published; if (x == last_published) return {}; last_published = x; return x;"

globals:
  - id: restart_confirmed
    type: bool
    restore_value: no
    initial_value: "false"
  - id: modbus_debugging
    type: bool
    restore_value: no
    initial_value: "false"
  - id: last_temp_update_ms
    type: uint32_t
    restore_value: no
    initial_value: "0"
  - id: comms_fault_latched
    type: bool
    restore_value: no
    initial_value: "false"
  - id: has_last_valid_temp
    type: bool
    restore_value: no
    initial_value: "false"
  - id: last_valid_temp
    type: float
    restore_value: no
    initial_value: "0.0"
  - id: last_temp_sample_ms
    type: uint32_t
    restore_value: no
    initial_value: "0"
  - id: emergency_stop_timestamp
    type: unsigned long
    restore_value: no
    initial_value: "0"
  - id: boot_complete
    type: bool
    restore_value: no
    initial_value: "false"
  - id: api_connection
    type: bool
    restore_value: no
    initial_value: "false"
  - id: home_assistant_api_client_count
    type: int
    restore_value: no
    initial_value: "0"
  - id: emergency_stop_fault
    type: bool
    restore_value: no
    initial_value: "false"
  - id: emergency_stop_manual_clear_pending
    type: bool
    restore_value: no
    initial_value: "false"

script:
  - id: write_temp_unit
    mode: queued
    then:
      - if:
          condition:
            lambda: |-
              return id(temperature_unit).state != "${temp_unit}";
          then:
            - select.set:
                id: set_temperature_unit
                option: "${temp_unit}"
  - id: restart_confirm_timeout
    mode: restart
    then:
      - delay: 10s
      - if:
          condition:
            lambda: "return id(restart_confirmed);"
          then:
            - logger.log:
                format: "Restart confirmation timed out"
                level: INFO
            - switch.turn_off: restart_confirmation
  - id: trigger_emergency_stop
    mode: restart
    then:
      - if:
          condition:
            lambda: |-
              return !id(emergency_stop).state;
          then:
            - lambda: |-
                id(emergency_stop_fault) = true;
                ESP_LOGE("safety", "EMERGENCY: Triggering Emergency Stop");
            - switch.turn_on: emergency_stop_internal
  - id: check_bambu_printer_online
    mode: restart
    then:
      - if:
          condition:
            lambda: |-
              bool boot_ready = id(boot_complete);
              bool api_ready = id(api_connection);
              bool printer_state_ready = id(printer_status_raw).has_state();
              if (!boot_ready || !api_ready || !printer_state_ready) {
                return false;
              }

              const std::string &printer_state = id(printer_status_raw).state;
              return printer_state == "off";
          then:
            - lambda: |-
                ESP_LOGE("safety", "EMERGENCY: Bambu printer is offline");
                id(trigger_emergency_stop)->execute();
  - id: auto_select_filament_preset
    mode: restart
    then:
      - lambda: |-
          const std::string &filament_raw = id(bambu_filament_type).state;
          const std::string current_preset = id(filament_temp_preset).current_option();
          const std::string filament_upper = to_upper_copy(filament_raw);

          const char *mapped_preset = lookup_filament_preset_name(filament_upper);

          if (mapped_preset != nullptr) {
            if (current_preset == mapped_preset) {
              ESP_LOGD(
                  "bambu",
                  "Chamber temperature preset already set to %s (%s filament)",
                  mapped_preset,
                  filament_raw.c_str());
              return;
            }

            auto call = id(filament_temp_preset).make_call();
            call.set_option(mapped_preset);
            call.perform();
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

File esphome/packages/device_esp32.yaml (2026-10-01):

#
# Bambu Chamber Heater Modbus Controller for Sinilink XY-SA/ST series temperature controllers.
# Shared Fahrenheit unit package for ESP8285 and ESP32-C6-Zero builds.
# Copyright (C) 2026    Katherine Dubé
#
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

#
# Main entrypoint for the unified chamber heater configuration.
# Keep the shared logic in packages/controller_shared.yaml and only switch
# the temperature-unit and device packages here as needed.
#

globals:
  - id: fan_low_rpm_since_ms
    type: uint32_t
    restore_value: no
    initial_value: "0"
  - id: status_led_mode
    type: int
    restore_value: no
    initial_value: "-1"

script:
  - id: check_fan_failure
    mode: restart
    then:
      - lambda: |-
          bool boot_ready = id(boot_complete);
          if (!boot_ready || id(emergency_stop).state) {
            id(fan_low_rpm_since_ms) = 0;
            return;
          }

          if (!id(printer_is_actively_printing).state) {
            id(fan_low_rpm_since_ms) = 0;
            return;
          }

          const float rpm = id(fan_rpm).state;
          if (isnan(rpm) || id(controller_status).state != "Active") {
            id(fan_low_rpm_since_ms) = 0;
            return;
          }

          if (rpm < ${fan_min_rpm}) {
            if (id(fan_low_rpm_since_ms) == 0) {
              id(fan_low_rpm_since_ms) = millis();
              return;
            }

            if ((millis() - id(fan_low_rpm_since_ms)) >=
                (${fan_fail_timeout_seconds}UL * 1000UL)) {
              id(fan_low_rpm_since_ms) = 0;
              ESP_LOGE(
                  "safety",
                  "EMERGENCY: Fan RPM %.0f below minimum %s for at least %s seconds while heater is active",
                  rpm,
                  "${fan_min_rpm}",
                  "${fan_fail_timeout_seconds}");
              id(trigger_emergency_stop)->execute();
            }
          } else {
            id(fan_low_rpm_since_ms) = 0;
          }

  - id: update_status_led
    mode: restart
    then:
      - lambda: |-
          if (!id(boot_complete)) {
            return;
          }

          StatusLedMode next_led_mode = compute_status_led_mode(
              id(emergency_stop).state,
              wifi::global_wifi_component->is_connected(),
              id(current_temperature).state,
              ${overtemp_led_warning_threshold},
              id(controller_status).state);

          if (id(status_led_mode) == static_cast<int>(next_led_mode)) {
            return;
          }
          id(status_led_mode) = static_cast<int>(next_led_mode);

          float red = 0.0f;
          float green = 1.0f;
          float blue = 0.0f;
          float brightness = 0.3f;
          const char *effect = "None";

          if (next_led_mode == STATUS_LED_EMERGENCY_STOP) {
            red = 1.0f;
            green = 0.0f;
            blue = 0.0f;
            brightness = 1.0f;
          } else if (next_led_mode == STATUS_LED_WIFI_DISCONNECTED) {
            red = 0.0f;
            green = 0.0f;
            blue = 1.0f;
            brightness = 0.75f;
            effect = "Fast Pulse";
          } else if (next_led_mode == STATUS_LED_OVERTEMP_WARNING) {
            effect = "Error Strobe";
          } else if (next_led_mode == STATUS_LED_HEATER_ACTIVE) {
            red = 1.0f;
            green = 0.5f;
            blue = 0.0f;
            brightness = 0.75f;
            effect = "Slow Pulse";
          }

          auto call = id(status_led).turn_on();
          call.set_rgb(red, green, blue);
          call.set_brightness(brightness);
          call.set_effect(effect);
          call.perform();

esp32:
  board: esp32-c6-devkitc-1
  flash_size: 8MB
  variant: esp32c6
  cpu_frequency: 160MHz
  framework:
    type: esp-idf
    version: latest
    advanced:
      enable_ota_rollback: true

esphome:
  includes:
    - ../include/status_led_helper.h
    - ../include/wifi_protocol_helper.h

light:
  - platform: esp32_rmt_led_strip
    id: status_led
    name: Status LED
    pin:
      number: ${status_led_pin}
      ignore_strapping_warning: true
    channel_colors: RGB
    num_leds: 1
    chipset: ws2812
    restore_mode: ALWAYS_OFF
    effects:
      - pulse:
          name: "Slow Pulse"
          transition_length: 1s
          update_interval: 1s
      - pulse:
          name: "Fast Pulse"
          transition_length: 0.5s
          update_interval: 0.5s
      - strobe:
          name: "Error Strobe"
          colors:
            - state: true
              brightness: 100%
              red: 100%
              green: 0%
              blue: 0%
              duration: 500ms
            - state: false
              duration: 500ms
    internal: true
    icon: "mdi:led-on"
    web_server:
      sorting_group_id: sorting_group_system

wifi:
  on_connect:
    - script.execute: update_status_led
  on_disconnect:
    - script.execute: update_status_led
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

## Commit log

2026-02-13 Initial release
    [temperature_controller.yaml]
2026-02-13 Updated version to 1.3
    [temperature_controller.yaml]
2026-02-14 Add Modbus Address Map and Safety Notes
    Added Modbus address map and safety notes for temperature controller.
2026-02-15 Numerous bug fixes, better fault handling, and code refactoring.
    [temperature_controller.yaml]
2026-02-15 Minor updates and refactoring.
    [temperature_controller.yaml]
2026-02-16 Fixed escape codes to degress
    [celsius.yaml, fahrenheit.yaml]
2026-02-16 Version changed 1.4.1
    [temperature_controller.yaml]
2026-02-16 Minor improvements
    [temperature_controller.yaml]
2026-02-16 Enhanced emergency stop time output to human readable format and minor changes.
    [temperature_controller.yaml]
2026-02-17 Added better handling of thermal overruns and situations where emergency stop is already trigger.
    [temperature_controller.yaml]
2026-02-17 Added comments to make the code easier to understand and a cooling mode bug fix.
    [temperature_controller.yaml]
2026-02-17 Minor bug fixes and optimizations
    [temperature_controller.yaml]
2026-02-17 Numerous bug fixes and code optimizations
    [temperature_controller.yaml]
2026-02-18 Add source files for wiring diagram
2026-02-18 Enhanced emergency stop handling during communication errors with Home Asssistant and the Bambu Lab integration. Added basic automations for filament type chamber heating presents when printing is st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
    [temperature_controller.yaml]
2026-02-19 Fixed printer status and filament type polling code to run on boot and when running.
    [temperature_controller.yaml]
2026-02-20 Expanded filament types and refactored code to be modular.
    [temperature_controller.yaml]
2026-02-22 Numerous performance and memory optimizations, code refactoring and several bug fixes.
    [temperature_controller.yaml]
2026-02-28 Numerous code optimizations and general clean-up.
    [BambuSauna_for_Sinilink.3mf, temperature_controller.yaml]
2026-03-01 Minor revision to housting cut out
    [BambuSauna_for_Sinilink.3mf]
2026-03-02 BambuSauna wiring image
2026-03-02 Refine README description for temperature controller
    Updated description for clarity and emphasis on the wireless module.
2026-03-02 BambuSauna housing images
2026-03-02 Update PTC heater installation details and known issues
    Clarified PTC heater installation instructions and updated known issues section for accuracy.
2026-03-02 Update hardware details in README
    Clarified specifications for the Sinilink Temperature Controller.
2026-03-02 Update known issues section for clarity
    Clarified example of mixed filament types in known issues.
2026-03-16 Start of ESP32-based repository with fan RPM monitoring
    [temperature_controller.yaml]
2026-03-16 Added ESP32-C6-Zero Case
    [esp32-c6_zero.3mf]
2026-03-17 Updated wiring diagram
2026-03-17 Logic fixes and simplification. Updated wiring diagrams.
    [temperature_controller.yaml]
2026-03-17 Updated fan RPM logic to be more robust
    [temperature_controller.yaml]
2026-03-17 Removed ESP8285 references
    [temperature_controller.yaml]
2026-03-17 Include a latch to prevent heater from turn on when the fan has failed.
    [temperature_controller.yaml]
2026-03-17 Updated README and wiring diagrams. Optimized code for performance improvements.
2026-03-19 Numerous logic fixes for preventing emergency stop from being overridden in the even of a fault.
    [temperature_controller.yaml]
2026-03-19 Revise README with new firmware upload details
    Updated build and upload information for chamber heater firmware.
2026-03-19 Merge safety improvements and optimizations from ESP32 branch
    Incorporates critical safety enhancements and performance improvements
    from the ESP32 branch while maintaining ESP8285 hardware compatibility.
    Safety Improvements:
    - Add emergency stop fault latch mechanism to prevent automatic clearing
    when triggered by fault conditions (sensor disconnection, temperature
    alarms, communication timeout, printer offline)
    - User must manually clear emergency stop after addressing root cause
    - Split emergency_stop into internal (Modbus) and external (template)
    switches to properly track fault vs manual activation
    - Update filament preset logic to respect fault latch state
    Performance Optimizat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
    [temperature_controller.yaml]
2026-03-19 Revision update to 1.6.1
    [temperature_controller.yaml]
2026-03-19 Optimized the safety logging calls and standardizing how the triggering_emergency_stop script gets called
    [temperature_controller.yaml]
2026-03-19 Updated version information
    [temperature_controller.yaml]
2026-03-20 Further optimizing of fault detection
    [temperature_controller.yaml]
2026-03-21 Updated logging messages
    [temperature_controller.yaml]
2026-03-21 Updating version to 1.6.2
    [temperature_controller.yaml]
2026-03-22 Numerous code logic fixes and optimizations. Includes several bug fixes.
    [temperature_controller.yaml]
2026-03-22 Fix issue with diff and merge from ESP32 branch.
    [temperature_controller.yaml]
2026-03-22 Whitespace updates
    [temperature_controller.yaml]
2026-04-02 Major refactoring to merge both the ESP32 and ESP8285 code bases
    [controller_shared.yaml, temp_controller.yaml, temp_controller_esp32.yaml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]
2026-04-02 Cleaning up directory structure
    [BambuSauna_for_Sinilink.3mf, controller_shared.yaml, esp32-c6_zero.3mf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]
2026-04-13 Fix: Using an external pullup, so this is not needed.
    [device_esp32_c6_zero.yaml]
2026-04-14 Updated 3D Model
    [esp32-c6_zero.3mf]
2026-04-14 Updating wiring diagram source files
2026-04-14 Numerous bug fixes related to LED usage before ready, improving API disconnect handling, and restricting fan faults to only when printing.
    [controller_shared.yaml]
2026-04-14 Additional bug fixes
    [controller_shared.yaml]
2026-04-15 Reverted change preventing manual pre-heating of chamber, and refactored several checks to make the code more streamlined.
    [controller_shared.yaml]
2026-04-15 Refactoring code to simplify reusing calls
    [controller_shared.yaml]
2026-04-15 Make GPIO pins configurable in a temp_controller specific yaml
    [temp_controller.yaml, temp_controller_esp32.yaml, temp_controller_esp8285.yaml]
2026-04-15 Removing duplicate code
    [controller_shared.yaml]
2026-05-04 Minor updates to address changes in ESPHome 2026.4
    [controller_shared.yaml]
2026-05-04 Adding esphome comment
    [controller_shared.yaml]
2026-06-05 Removes the stale dependency on id(printer_is_actively_printing).state, which was the path allowing finish to set the preset to Off and then immediately re-select a filament preset afterward.
    [controller_shared.yaml]
2026-07-11 Performance improvements and code optimizations
    [controller_shared.yaml]
2026-08-05 Numerous improvements
    [controller_shared.yaml, temp_controller_esp32.yaml]
2026-08-12 Remove ESPHome deprecated options
    [controller_shared.yaml]
2026-10-01 Minor esphome deprecation fixes
    [controller_shared.yaml]

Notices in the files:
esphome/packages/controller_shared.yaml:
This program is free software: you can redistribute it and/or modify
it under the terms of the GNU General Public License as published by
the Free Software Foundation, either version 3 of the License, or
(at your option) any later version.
